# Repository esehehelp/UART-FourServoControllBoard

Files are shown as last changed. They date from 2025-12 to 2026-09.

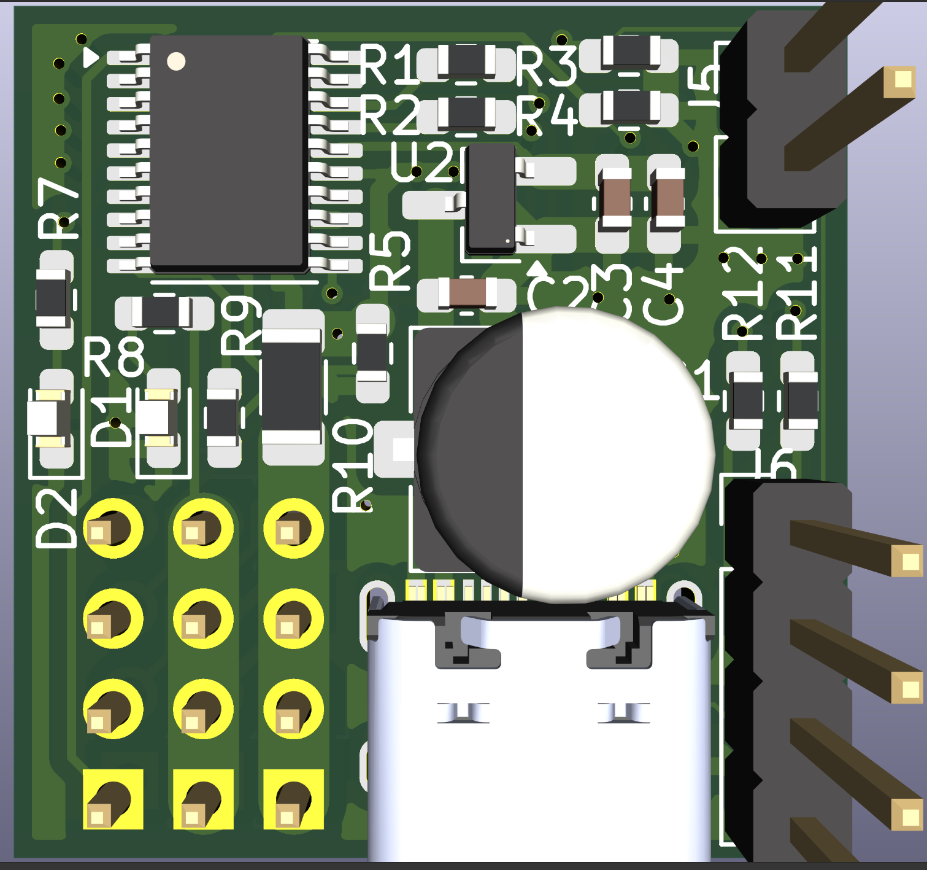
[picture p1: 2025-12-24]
hardware/img/boardfrontview.png

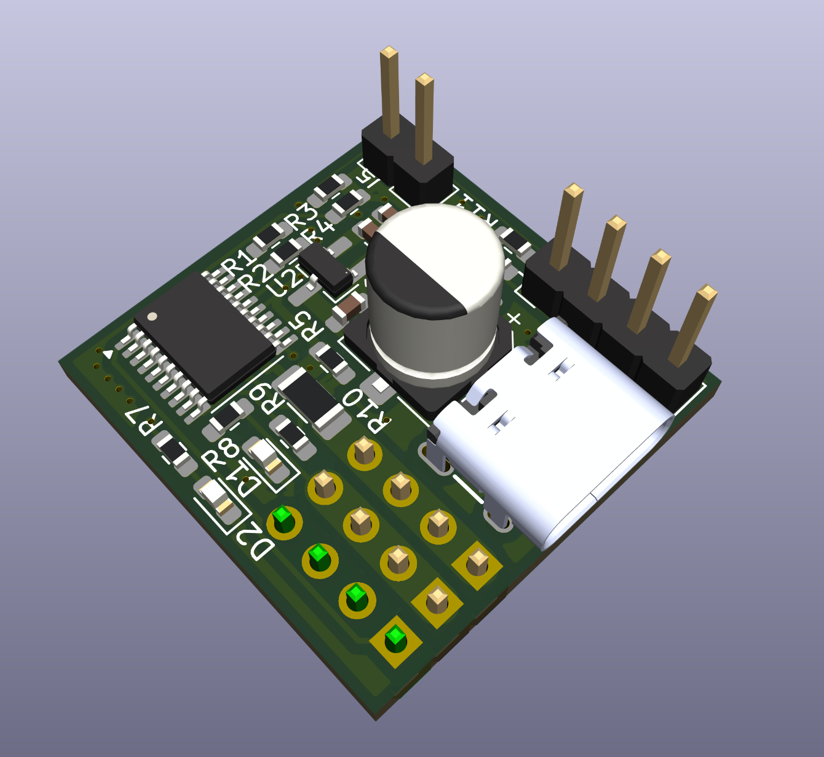
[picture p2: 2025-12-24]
hardware/img/board25dview.png

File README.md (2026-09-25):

# UART-FourServoControllBoard

## 概要 (Overview)

**UART-FourServoControllBoard** (以下UART-FSCB) は、わずか **22.82mm x 23.62mm** のサイズに、ロボットアーム制御に必要な機能をおおよそ詰め込んだ4軸スマートサーボコントローラ
従来のPCA9685等の単なるPWMドライバとは異なり、**電流・電圧・温度監視**、**USB-PD** 機能を搭載。MG996Rなどのハイパワーサーボ使用時でも、電流値と消費電力を監視しながら安全に駆動することが可能

## 特徴 (Features)

* **超小型サイズ:** 22.82mm x 23.62mm
* **USB PD対応:** CCピン制御により、モバイルバッテリーやPD充電器から電源を直接引き出し可能
  * 固定電圧 PDO に加え PPS (APDO) による電圧指定に対応 (`0x06` コマンド, mV 単位)
  * USB (CDC) 経由の通信対応
  * DLM (ブートローダ) 移行: `0xF0` コマンド、または背面PADに4.7k抵抗を直列でショート
    * USB経由の書き込み可能
* **電流監視機能:**
  * ローサイド電流検知回路を搭載（CH32X035内蔵OPA + 10mΩシャント抵抗）
  * サーボの負荷状態をモニタリングし、過負荷時の緊急停止などが実装可能
  * 停止閾値などは別途ソフトウェアで書き込み可能
* **電圧監視機能**
  * 分圧抵抗によって電圧を監視可能
  * PPSと組み合わせたフィードバック制御も行う予定
* **温度監視**
  * NTCサーミスタによってVBUS-GNDに近い位置の温度計測が可能
* **PC用GUI** (`software/`)
  * Go + Wails (React) 製。USB 接続したボードを自動検出
  * 電圧・電流・温度・サーボフィードバックのリアルタイムプロット
  * サーボ 4ch / LED 2ch / USB-PD 電圧の操作、サーボ位置キャリブレーション
* **MCU:** WCH CH32X035F7P6 (RISC-V, 48MHz)
* **制御IF:** 1Wire-UART, USB
* **その他:**
  * 外部電源入出力ピンヘッダx2 (バッテリー駆動対応、BMS無し)
  * デイジーチェーン対応 (1Wire-UARTかつ電源ピン仕様時)
  * デバック用1.27ピンヘッダ搭載
  * 片面実装
  * 手ハンダ可能 (難易度は高い)
  * XC6206 LDOによる安定した3.3V系電源
    * より高耐圧な互換LDOによるさらなる高電圧対応

## 仕様 (Specifications)

| 項目 | 内容 |
| :--- | :--- |
| **MCU** | WCH CH32X035F7P6 (TSSOP-20) |
| **入力電圧** | USB VBUS (5V-20V) または EXT_IN (5V〜20V) |
| **ロジック電圧** | 3.3V (XC6206 LDO内蔵) |
| **出力チャンネル** | 4PWM |
| **通信** | 1-Wire UARTx2 (Default: 115200bps, 8N1) |
| **電流検知** | 0 〜 6.8A (Full Scale) |
| **コンデンサ** | 100uF / 35V (Polymer) + 22uF (Ceramic) |
| **基板サイズ** | 22.86mm x 23.62mm |

### サーボチャンネルと物理ピン

チャンネル番号は基板上のピン並び順と一致しません (ピン番号順に **CH3 → CH0 → CH1 → CH2**)。

| MCU ピン No. | MCU ピン | チャンネル |
| :--- | :--- | :--- |
| 5 | PC1 | CH3 |
| 6 | PA0 | CH0 |
| 7 | PA1 | CH1 |
| 9 | PA3 | CH2 |

## リポジトリ構成

| ディレクトリ | 内容 |
| :--- | :--- |
| `firmware/` | CH32X035 用ファームウェア (PlatformIO)。通信仕様は [`firmware/docs/PROTOCOL.md`](firmware/docs/PROTOCOL.md) |
| `software/` | PC 用 GUI (Go + Wails)。詳細は [`software/README.md`](software/README.md) |
| `hardware/` | KiCad 9.0 設計データ |

## 開発環境 (Development)

* **IDE:** Goland, CLion
* **Firmware:** PlatformIO (`platform = ch32v`)
* **Writer:** WCH-LinkE、または USB 経由 (DLM + wchisp)

### ファームウェアのビルド・書き込み

```bash
cd firmware
pio run                 # ビルド
pio run -t upload       # WCH-LinkE 等で書き込み

# USB 経由 (0xF0 で DLM に移行してから wchisp で書き込み)
python test/dlm_upload.py <PORT> .pio/build/genericCH32X035F7P6/firmware.bin
```

### GUI のビルド

```bash
cd software
~/go/bin/wails build    # -> build/bin/servo-controller (Wails CLI が必要)
go test ./pkg/... ./test/...   # Go ユニットテスト
```

## 設計データ (Design Data)

* **EDA:** KiCad 9.0
* **PCB:** 2層基板 (1.6mm厚推奨)

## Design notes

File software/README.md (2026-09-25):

# Servo Controller GUI (Go + Wails)

UART-FSCB を USB 経由で操作・監視する PC 用 GUI。バックエンドは Go、フロントエンドは React (TypeScript) で、[Wails v2](https://wails.io/) で 1 つの実行ファイルにまとめています。

## 機能

- **自動接続**: シリアルポートを走査し、`0x02` (センサー読み出し) に応答したポートに接続
  - ボードの USB VID (WCH `0x1A86`) を持つポート → その他の USB ポート → `ttyUSB` → `ttyACM` / `COM*` → `ttyS` の順に試行
- **リアルタイムモニタリング** (~30 fps)
  - 電圧 (V)・電流 (mA)・温度 (°C)・サーボフィードバック CH0-3
  - 電圧・電流は Kalman フィルタで平滑化
  - 2 秒間応答がないとデータを無効扱いにし、ステータスバーに "No sensor data" を表示
- **サーボ制御** (`0x01`): 4ch スライダー、500–2500 µs (ファームウェアのデフォルト範囲)
- **LED 制御** (`0x30`): LED1 / LED2 それぞれ 0–255
- **USB-PD 電圧** (`0x06`): 5 / 9 / 15 / 20 V プリセット + 任意電圧 (mV)
- **位置キャリブレーション** (`0x07`)
  1. サーボをセンター (1500 µs) へ移動
  2. PWM を停止 (`0x09`) し、ユーザがアームを最小位置へ動かして Confirm
  3. 最大位置へ動かして Confirm
  4. 2 点のフィードバック値から傾き・切片を計算しフラッシュへ保存

チャンネル番号と基板上のピンの対応は [`firmware/docs/PROTOCOL.md`](../firmware/docs/PROTOCOL.md) を参照してください。

## ビルド

### 前提条件

- Go (go.mod 参照)
- Node.js / npm (フロントエンド)
- Wails CLI v2: `go install github.com/wailsapp/wails/v2/cmd/wails@latest`
- Linux の場合は Wails の依存パッケージ (GTK3, WebKit2GTK)。`wails doctor` で確認できます
- シリアルポートアクセスのため CGO が必要

### コマンド

```bash
cd software

~/go/bin/wails build                          # -> build/bin/servo-controller
~/go/bin/wails build -platform windows/amd64  # Windows 向け
~/go/bin/wails dev                            # ホットリロード付き開発サーバ
go test ./pkg/... ./test/...                  # Go ユニットテスト
```

## プロジェクト構成

```
software/
├── main.go                    # Wails アプリ起動
├── app.go                     # JS から呼べるメソッド、イベント送出 (~30 fps)
├── config/config.go           # プロトコル定数・スケール係数・各種パラメータ
├── pkg/
│   ├── serial/manager.go      # パケット (Marshal/Unmarshal, CRC8)、ポート検出、送受信 goroutine
│   ├── device/controller.go   # 高レベル API (SetServo, SetLED, ...)、センサーデータ解析
│   ├── device/packet.go       # pkg/serial のパケット型のエイリアス
│   ├── data/ringbuffer.go     # スレッドセーフなリングバッファ + 1D Kalman フィルタ
│   └── calibration/           # 位置キャリブレーションの状態機械
├── frontend/src/              # React UI (StatusBar, ServoControl, LEDControl, PDControl,
│                              #           CalibrationPanel, SensorGraph)
└── test/                      # パケットのユニットテスト
```

## 通信フロー

```
React UI ──(Wails binding)──> App ──> Controller ──> serial.Manager ──> USB-CDC ──> Firmware
React UI <──(Wails events)─── App <── Controller <── rx channel     <──
```

- `serial.Manager` は受信 goroutine でパケットを切り出し、容量 128 の channel に流します (溢れた場合はログに累計破棄数を出力)
- `Controller` は受信パケットの処理と定期的なセンサー要求を 1 つの goroutine で行います
- フロントエンドへは `sensor-data` / `plot-data` / `status` / `cal-status` イベントで通知します

## プロトコル

パケット形式・コマンド一覧は [`firmware/docs/PROTOCOL.md`](../firmware/docs/PROTOCOL.md) を参照してください。

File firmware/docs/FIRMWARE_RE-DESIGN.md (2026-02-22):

# CH32X035F7P6 ファームウェア設計変更ログ

## ハードウェア制約と解決策
- **ピン数**: TSSOP20 (F7P6) のためリマップが必須。
- **USART2 vs PWM**: PA3 で USART2_RX がデフォルトだが、サーボ PWM と競合する。
  - **解決**: USART2 を 1-Wire Half-Duplex に設定し、RXピンを使用しない構成とする。さらにリマップにより論理的なRXピンを PA5 側へ逃がす（実際には USART4 と共有）。
- **USART4 (UART_B)**: PA5 を 1-Wire TX として使用するため、`AFIO_PCFR1` でリマップを適用。
- **OPA2 vs UART**: PA2 (USART2_TX) と PA5 (USART4_TX) が OPA2 のピンと重なっている。
  - **解決**: OPA2 を内部出力モード (`MODE2=0`) に設定して PA2 を解放し、負入力 (`NSEL2=111`) を切り替えて PA5 を解放。

## ソフトウェア設計
- **時間管理の移行**: `Delay_Ms` (SysTick) との干渉を避けるため、プロジェクト全体の時間管理を `TIM3` (1ms割り込み) に移行。
- **プロトコルスタック**: 全ての UART/USB インターフェースで共通のパーサーを使用し、リングバスを構成。
- **USB PD**: PPS 対応を完了。起動時は必ず 5V で安全を確保。

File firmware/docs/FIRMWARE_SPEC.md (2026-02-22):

# CH32X035F7P6 ファームウェア仕様 (v2.1)

## 1. 周辺機能の割り当て
| 機能 | 周辺機能 | ピン / チャンネル | 備考 |
| :--- | :--- | :--- | :--- |
| **Servo CH0** | TIM2_CH1 | PA0 | |
| **Servo CH1** | TIM2_CH2 | PA1 | |
| **Servo CH2** | TIM2_CH4 | PA3 | |
| **Servo CH3** | TIM1_CH2 | PC1 | Full Remap 適用 |
| **UART_A** | USART2 | PA2 | 1-Wire モード |
| **UART_B** | USART4 | PA5 | 1-Wire モード / Partial Remap 1 |
| **V_SENSE** | ADC_IN6 | PA6 | 電圧監視 (5.1k/1k分圧) |
| **T_SENSE** | ADC_IN9 | PB1 | 温度監視 (NTC 22k) |
| **I_SENSE** | OPA2 / ADC_IN4 | PA7(+) / PA4(O) | 電流監視 (10mOhm / PGA x32) |
| **LED** | GPIO | PB12 | ステータス表示 (Active-High) |
| **1ms Tick** | TIM3 | 内部 | 時間管理・DLMカウントダウン用 |

## 2. UART 構成とリマップ
- **USART2 (PA2)**: デフォルト設定。`HDSEL` ビットにより 1-Wire モードで使用。
- **USART4 (PA5)**: `AFIO_PCFR1` の `USART4_REMAP` ビットを `001` に設定し、TX 機能を PA5 に割り当て。同様に `HDSEL` で 1-Wire 運用。
- **パケットルーティング**: 受信したパケットのターゲットIDが自ノードでない場合、受信したポート以外（UART2, UART4, USB）へパケットをブリッジします。

## 3. OPA2 と電流計測
- **構成**: PGA モード、ゲイン x32。
- **ピン競合回避**: 
  - `MODE2 = 0` により OPA2 出力を内部の PA4 (ADC_IN4) に固定し、USART2 で使用する PA2 を解放。
  - `NSEL2 = 111` により負入力を PA5 から切り離し、USART4 で使用する PA5 を解放。

## 4. 時間管理
- **TIM3**: 1ms 周期の割り込みを生成。
- **用途**: センサーデータの受信タイムアウト監視、DLM（ISPモード）移行への秒数カウント、将来的な時間ベースの制御用。
- **Delay**: 標準の `Delay_Ms` は SysTick を停止させるため、経過時間の計測には TIM3 のカウント（`g_ms_ticks`）を使用すること。

## 5. ファームウェアアップデート (DLM)
- **トリガー**: UART コマンド `0xF0`。
- **シーケンス**:
    1. `0xF0` 受信後、`g_dlm_requested` フラグをセット。
    2. LED が高速点滅 (5Hz)。
    3. 約2秒後、ソフトウェアリセットを実行し、System Bootloader (ISP) モードへ移行。
- **ツール**: `wchisp` または `WCHISPTool`。

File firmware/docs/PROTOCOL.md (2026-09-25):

# UART Four Servo Control Board 通信プロトコル仕様 (v2.3)

## 1. 物理層
- **通信方式**: 1-Wire 半二重 UART (Ring Bus 構成)
- **インターフェース**: USB (CDC), UART2, UART4
- **ボーレート**: 115200 bps (8N1)
- **デフォルトデバイスID**: `0x01` (ホストは `0x00`, ブロードキャストは `0xFF`)

## 2. パケット構造
すべてのパケットは以下の形式で構成されます。数値は特に指定がない限りビッグエンディアン（Big-Endian）です。

| Offset | Field | Value | Description |
| :--- | :--- | :--- | :--- |
| 0 | Header | 0xAA | パケット開始フラグ |
| 1 | Target ID | 0xXX | 送信先デバイスID |
| 2 | Source ID | 0xXX | 送信元デバイスID |
| 3 | Command | 0xXX | 命令コード |
| 4 | Length | N | データ部のバイト数 |
| 5..5+N-1 | Data | ... | 命令に応じたデータ |
| 5+N | CRC8 | 0xXX | HeaderからData末尾までのCRC |

- **最大パケット長**: 128 bytes (ファームウェアの受信バッファ長)。したがって Data 部 (N) は最大 **122 bytes**。
  Length に 122 を超える値を持つパケットはファームウェアで破棄されます。

### サーボチャンネルと物理ピンの対応
チャンネル番号はタイマーチャンネルの割り当て順であり、基板上のピン並び順とは一致しません。

| 物理ピン (MCU pin No.) | MCU ピン | チャンネル | タイマー |
| :--- | :--- | :--- | :--- |
| 5 | PC1 | **CH3** | TIM1_CH2 (Full Remap) |
| 6 | PA0 | **CH0** | TIM2_CH1 |
| 7 | PA1 | **CH1** | TIM2_CH2 |
| 9 | PA3 | **CH2** | TIM2_CH4 |

ピン番号順に並べると **CH3 → CH0 → CH1 → CH2** となります (`firmware/docs/pinassign.csv` 参照)。

## 3. 命令コード (Command)

### 0x01: Write (サーボ個別設定)
特定のチャンネルのサーボパルス幅を設定します。
電源投入直後は全チャンネルが PWM 停止 (出力 LOW、`0x09` と同じ状態) で、`0x01` / `0x03` を受信したチャンネルから駆動を開始します。
パルス幅はチャンネルごとのキャリブレーション範囲 (デフォルト 500-2500μs) にクランプされます。
- **Data**: 3 bytes
  - `[0]`: Channel Index (0-3)
  - `[1:2]`: Pulse Width (uint16, 500-2500μs)

### 0x02: Read (センサー読み出し)
各種センサー情報とサーボの現在位置を取得します。
- **Request Data**: 1 byte (0x00: All)
- **Response Data (0x82)**: 15 bytes
  - `[0]`: Data Type (0x00)
  - `[1:2]`: Bus Voltage (ADC Raw Value)
  - `[3:4]`: MCU Temperature (ADC Raw Value)
  - `[5:6]`: Total Current (ADC Raw Value)
  - `[7:14]`: Servo 0-3 Feedback (μs, 16-bit x 4 channels)
    - 保存されたキャリブレーション係数を用いて計算された値が返ります。

### 0x03: SyncWrite (全サーボ同時設定)
全4チャンネルのパルス幅を一度に設定します。
- **Data**: 8 bytes
  - `[0:1]`: CH0 Pulse, `[2:3]`: CH1 Pulse, `[4:5]`: CH2 Pulse, `[6:7]`: CH3 Pulse (all uint16)

### 0x04: CfgWrite (システム設定)
デバイス自体の設定を変更します。
- **Sub-Commands**:
  - `[0:1] = [0x01, NewID]`: デバイスIDを変更し、Flashに保存します。
  - `[0:1] = [0x02, Role]`: デバイスのロールを変更し、Flashに保存します。

### ~~0x05: STATIC_LED~~ (廃止 → `0x30` に移行)

### 0x30: LED_SET (LED制御)
基板上のインジケータLEDを個別に制御します。
- **Data**: 2 bytes
  - `[0]`: Channel (0=LED1/PB12/Active-High, 1=LED2/PC3/Active-Low)
  - `[1]`: Duty (0-255, soft PWM)

### 0x06: Set Voltage (USB PD PPS設定)
USB PD PPS対応電源を使用している場合、供給電圧を変更します。
- **Data**: 2 bytes
  - `[0:1]`: Target Voltage (uint16, unit: mV)

### 0x07: Set Calibration (キャリブレーション保存)
特定チャンネルのキャリブレーションパラメータと安全範囲を Flash に保存します。
- **Data**: 13 bytes
  - `[0]`: Channel Index (0-3)
  - `[1:4]`: Slope (float32, little-endian)
  - `[5:8]`: Intercept (float32, little-endian)
  - `[9:10]`: Min Pulse (uint16, big-endian)
  - `[11:12]`: Max Pulse (uint16, big-endian)
- Slope / Intercept はファームウェアが `memcpy` で float に直接コピーするため **little-endian** です (パケット全体の既定であるビッグエンディアンの例外)。
- `Min Pulse >= Max Pulse` のデータは無視され、保存されません。

### 0x08: Get Calibration (キャリブレーション取得)
保存されている設定を読み出します。
- **Request Data**: 1 byte (Channel Index)
- **Response Data (0x88)**: 13 bytes (0x07 と同形式)

### 0x09: Servo Free (PWM停止)
指定チャンネルのPWM出力を停止し、サーボを脱力させます。再度動かすには `0x01` または `0x03` を送信します。
- **Data**: 1 byte (ch_mask: bit0=CH0, bit1=CH1, bit2=CH2, bit3=CH3)

### 0xA0: Ping (デバイス探索要求)
リングバス上のデバイスを探索します。動作は受信したボードのロール (`0x04` CfgWrite の Role) によって異なります。
- **Data**: なし (0 bytes)
- **ROLE_HOST (0x01) のボードが USB から受信した場合**:
  Target=`0xFF` (ブロードキャスト)、Source=自身のデバイスID で Ping を UART2 (リング下流) へ送信し、100 ms の探索ウィンドウを開始します。
- **ROLE_DEVICE (0x00) のボードが受信した場合**:
  受信したインターフェースへ `0xA1` (Pong) を返信します (Target=Ping の Source、Data=`[device_id]`)。

### 0xA1: Pong (デバイス探索応答)
- **デバイス → ホストボード**: Data 1 byte (`[0]`: 応答したデバイスのID)。
  ROLE_HOST のボードは探索ウィンドウ中に受信した ID を最大 16 個まで記録します。
- **ホストボード → PC (USB)**: 探索開始から 100 ms 経過後、Target=`0x00` で送信します。
  - **Data**: N bytes (N = 発見したデバイス数、0-16)。各バイトが発見したデバイスID。

> 注: 現在の実装では、ブロードキャスト (`0xFF`) 宛パケットは受信したデバイスで実行され、リングの次段へは転送されません。

### 0xF0: DLM (Download Mode)
ブートローダー(ISP)モードへ移行するためのカウントダウンを開始します。

## 4. CRC8 計算
- **多項式**: `0x07` (x^8 + x^2 + x + 1)
- **初期値**: `0x00`
- **対象**: Header から Data の末尾まで

```c
uint8_t crc8(const uint8_t *data, size_t len) {
    uint8_t crc = 0;
    for (size_t i = 0; i < len; i++) {
        crc ^= data[i];
        for (int j = 0; j < 8; j++) {
            if (crc & 0x80) crc = (crc << 1) ^ 0x07;
            else crc <<= 1;
        }
    }
    return crc;
}
```

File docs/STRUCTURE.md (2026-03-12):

# Documentation Structure

## 既存ドキュメント配置

### Root Level
- **README.md** - プロジェクト概要 (特徴・仕様・開発環境)
- **CLAUDE.md** - AI向けコンテキスト

### firmware/docs/
- **PROTOCOL.md** - プロトコル仕様詳細
- **FIRMWARE_SPEC.md** - ファームウェア機能仕様
- **FIRMWARE_RE-DESIGN.md** - 再設計ノート
- **pinassign.csv** - ピンアサイン（簡略版）

### software/
- **README.md** - Go GUI機能説明

### docs/ (新規)
- **PINASSIGN_VERIFIED.csv** - ソースコード検証版ピンアサイン
- **STRUCTURE.md** - このファイル

## 整理指針

各ドキュメントは機能要件・問題ごとに分離されるべき:

1. **PROTOCOL.md** - コマンド仕様のみ
2. **FIRMWARE_SPEC.md** - モジュール機能のみ
3. **pinassign.csv** - 既存版は簡略版、PINASSIGN_VERIFIED.csvはソース検証版
4. **README.md** - 全体概要のみ
5. **software/README.md** - GUI機能説明のみ

汎用的な「統一ドキュメント」は不要。各ドキュメントは独立して参照可能であること。

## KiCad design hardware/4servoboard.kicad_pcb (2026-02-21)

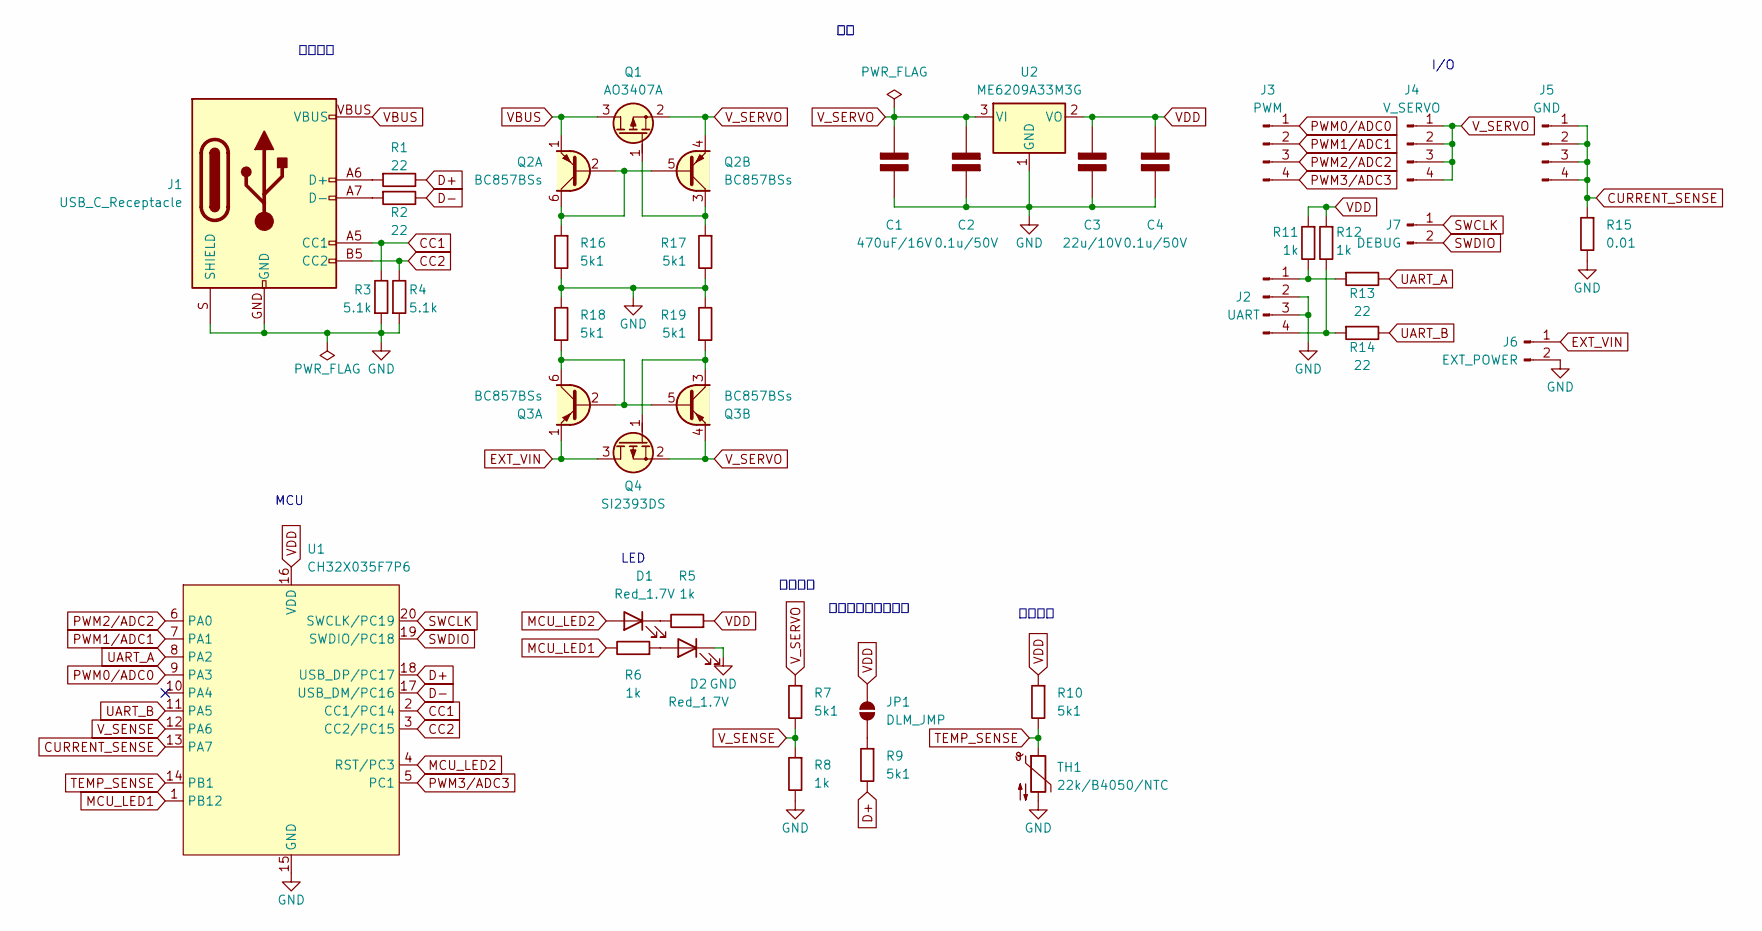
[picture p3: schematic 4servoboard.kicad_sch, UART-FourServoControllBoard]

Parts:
C1: 470uF/16V; CP_Elec_6.3x7.7; Rating V
C2, C4: 0.1u/50V; C_0603_1608Metric; Rating V
C3: 22u/10V; C_0603_1608Metric; Rating V
D1, D2: Red_1.7V; LED_0603_1608Metric
J1: USB_C_Receptacle; USB-C_16-HandSolder
J2: UART; PinHeader_1x04_P2.54mm_Vertical
J3: PWM; PinHeader_1x04_P2.54mm_Vertical
J4: V_SERVO; PinHeader_1x04_P2.54mm_Vertical
J5: GND; PinHeader_1x04_P2.54mm_Vertical
J6: EXT_POWER; TerminalBlock_Xinya_XY308-2.54-2P_1x02_P2.54mm_Horizontal
J7: DEBUG; PinHeader_1x02_P2.54mm_Vertical
JP1: DLM_JMP; SolderJumper-2_P1.3mm_Open_Pad1.0x1.5mm
Q1: AO3407A; SOT-23
Q2, Q3: BC857BSs; SOT-363_SC-70-6
Q4: SI2393DS; SOT-23
R1, R2, R13, R14: 22; R_0603_1608Metric
R3, R4: 5.1k; R_0603_1608Metric
R5, R6, R8, R11, R12: 1k; R_0603_1608Metric
R7, R9, R10, R16, R17, R18, R19: 5k1; R_0603_1608Metric
R15: 0.01; R_1206_3216Metric
TH1: 22k/B4050/NTC; R_0603_1608Metric
U1: CH32X035F7P6; TSSOP-20_4.4x6.5mm_P0.65mm
U2: ME6209A33M3G; SOT-23

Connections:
CC1: J1.A5 (CC1), R3.2, U1.2 (CC1/PC14)
CC2: J1.B5 (CC2), R4.2, U1.3 (CC2/PC15)
CURRENT_SENSE: J5.1, J5.2, J5.3, J5.4, R15.1, U1.13 (PA7)
D+: R1.2, R9.2, U1.18 (USB_DP/PC17)
D-: R2.2, U1.17 (USB_DM/PC16)
EXT_VIN: J6.1, Q3.1 (E1), Q4.3 (D)
GND: C1.2 (-), C2.1 (+), C3.2 (-), C4.2 (-), D2.1 (K), J1.GND, J1.S (SHIELD), J2.2, J2.3, J6.2, R3.1, R4.1, R8.2, R15.2, R16.2, R17.2, R18.2, R19.2, TH1.2, U1.15 (GND), U2.1 (GND)
MCU_LED1: R6.2, U1.1 (PB12)
MCU_LED2: D1.2 (A), U1.4 (RST/PC3)
unnamed: D1.1 (K), R5.2
unnamed: D2.2 (A), R6.1
unnamed: J1.A6 (D+), J1.B6 (D+), R1.1
unnamed: J1.A7 (D-), J1.B7 (D-), R2.1
unnamed: J2.1, R11.2, R13.1
unnamed: J2.4, R12.2, R14.1
unnamed: JP1.1 (A), R9.1
unnamed: Q1.1 (G), Q2.3 (C2), R17.1
unnamed: Q2.2 (B1), Q2.5 (B2), Q2.6 (C1), R16.1
unnamed: Q3.2 (B1), Q3.5 (B2), Q3.6 (C1), R18.1
unnamed: Q3.3 (C2), Q4.1 (G), R19.1
PWM0/ADC0: J3.1, U1.9 (PA3)
PWM1/ADC1: J3.2, U1.7 (PA1)
PWM2/ADC2: J3.3, U1.6 (PA0)
PWM3/ADC3: J3.4, U1.5 (PC1)
SWCLK: J7.1, U1.20 (SWCLK/PC19)
SWDIO: J7.2, U1.19 (SWDIO/PC18)
TEMP_SENSE: R10.2, TH1.1, U1.14 (PB1)
UART_A: R13.2, U1.8 (PA2)
UART_B: R14.2, U1.11 (PA5)
VBUS: J1.VBUS, Q1.3 (D), Q2.1 (E1)
VDD: C3.1 (+), C4.1 (+), JP1.2 (B), R5.1, R10.1, R11.1, R12.1, U1.16 (VDD), U2.2 (VO)
V_SENSE: R7.2, R8.1, U1.12 (PA6)
V_SERVO: C1.1 (+), C2.2 (-), J4.1, J4.2, J4.3, J4.4, Q1.2 (S), Q2.4 (E2), Q3.4 (E2), Q4.2 (S), R7.1, U2.3 (VI)

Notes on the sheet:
電圧計測
MCU
I/O
温度計測
LED
コネクタ
ダウンロードモード

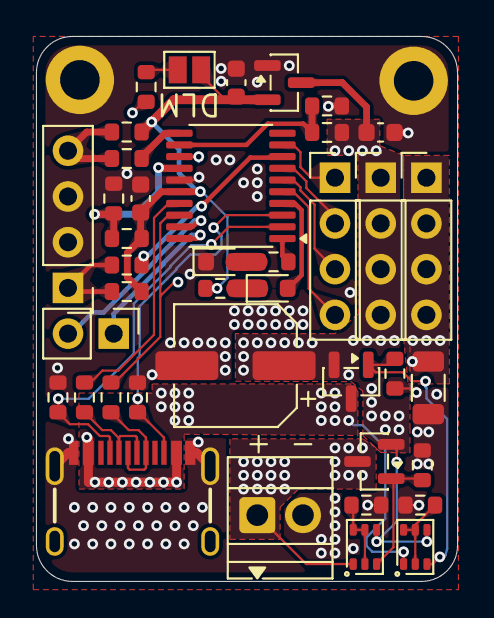
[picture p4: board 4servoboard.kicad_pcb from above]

Board: 4 copper layers, 23.4 x 30.3 mm, 40 parts (0 on the bottom side), 33 nets.

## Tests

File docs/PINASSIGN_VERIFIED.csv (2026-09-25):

" Pin Assignment - Verified from Source Code Source code verified pin assignments for CH32X035F7P6 (TSSOP-20) All peripheral mappings extracted from firmware source files. "
Pin | Port | MCU Function | Hardware Use | Peripheral | ADC Channel | Source File | Notes
1 | PB12 | GPIO | LED1 | GPIO_Out_PP | none | led.c:9 | Active-High LED output
2 | PC14 | USB-PD CC1 | CC1 | USB-PD | none | usb_pd.c | USB-PD CC1 — implemented; voltage negotiation and PPS support (usb_pd.c)
3 | PC15 | USB-PD CC2 | CC2 | USB-PD | none | usb_pd.c | USB-PD CC2 — implemented; voltage negotiation and PPS support (usb_pd.c)
4 | PC3 | GPIO | LED2 | GPIO_Out_PP | none | led.c:16 | Active-Low; CMP1_N0 must be disabled (led.c:39)
5 | PC1 | TIM1_CH2 | Servo CH3 PWM + FB | TIM1 (Full Remap) | ADC_CH11 | servo.c:45 | Full Remap AFIO PCFR1[17:15]=011
6 | PA0 | TIM2_CH1 | Servo CH0 PWM + FB | TIM2_CH1 | ADC_CH0 | adc.h:12 | Servo 0 output and feedback ADC
7 | PA1 | TIM2_CH2 | Servo CH1 PWM + FB | TIM2_CH2 | ADC_CH1 | adc.h:13 | Servo 1 output and feedback ADC
8 | PA2 | USART2_TX/RX | UART Ring (Upstream) | USART2 (1-Wire) | none | UART.c:L20 | 1-Wire Ring topology Upstream; 115200 bps 8N1
9 | PA3 | TIM2_CH4 | Servo CH2 PWM + FB | TIM2_CH4 | ADC_CH3 | adc.h:14 | Servo 2 output and feedback ADC
10 | PA4 | OPA2_OUT | Current Sense | OPA2 Output + ADC | ADC_CH4 | adc.h:9 | OPA2 current sense amplifier output
11 | PA5 | USART4_TX/RX | UART Ring (Downstream) | USART4 (Remap 001) | none | UART.c:L45 | 1-Wire Ring topology Downstream; Remap 001: AFIO PCFR1[4:3]=001
12 | PA6 | ADC input | Voltage Sense | ADC | ADC_CH6 | adc.h:7 | Power supply voltage measurement (6.1:1 divider)
13 | PA7 | OPA2_P0 | Current Sense Input | OPA2 Non-Inverting | none | adc.c:L20 | Shunt resistor (10mΩ) output to OPA2 input
14 | PB1 | ADC input | Temperature Sense | ADC | ADC_CH9 | adc.h:8 | NTC thermistor temperature measurement
15 | GND | Ground | Ground | Power | none |  | -
16 | VDD | Supply | 3.3V | Power | none | servo.c:36 | XC6206 LDO output (5-20V input → 3.3V)
17 | PC16 | USB | USB D- | USB | none | protocol.h | USB 2.0 Full-Speed
18 | PC17 | USB | USB D+ | USB | none | protocol.h | USB 2.0 Full-Speed
19 | PC18 | SWD | Debug SWDIO | Debug (SWD) | none | - | JTAG/SWD Debug Port
20 | PC19 | SWD | Debug SWCLK | Debug (SWD) | none | - | JTAG/SWD Debug Port

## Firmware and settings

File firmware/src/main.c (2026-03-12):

#include "debug.h"
#include "ch32x035_usbfs_device.h"
#include "UART.h"
#include "servo.h"
#include "adc.h"
#include "protocol.h"
#include "app.h"
#include "dlm_jump.h"
#include "usb_pd.h"
#include "led.h"
#include "usb_desc.h"
#include <stdio.h>

volatile uint32_t g_ms_ticks = 0;

/* Build USB serial number string from chip unique ID (0x1FFFF7E8, 8 bytes)
 * MySerNumInfo format: [len=0x22][type=0x03][16 hex chars in UTF-16LE] */
static void USB_BuildSerialFromUID(void) {
    static const char hex[] = "0123456789ABCDEF";
    const uint8_t *uid = (const uint8_t *)0x1FFFF7E8;
    for (int i = 0; i < 8; i++) {
        MySerNumInfo[2 + i*4 + 0] = hex[(uid[i] >> 4) & 0xF];
        MySerNumInfo[2 + i*4 + 1] = 0;
        MySerNumInfo[2 + i*4 + 2] = hex[uid[i] & 0xF];
        MySerNumInfo[2 + i*4 + 3] = 0;
    }
}
volatile uint32_t g_dlm_timer = 0;

void TIM3_IRQHandler(void) __attribute__((interrupt("WCH-Interrupt-fast")));
void TIM3_IRQHandler(void) {
    if (TIM_GetITStatus(TIM3, TIM_IT_Update) != RESET) {
        g_ms_ticks++;
        if (g_dlm_requested && g_dlm_timer > 0) {
            g_dlm_timer--;
        }
        TIM_ClearITPendingBit(TIM3, TIM_IT_Update);
    }
}

void Timer3_Init(void) {
    TIM_TimeBaseInitTypeDef TIM_TimeBaseStructure = {0};
    RCC_APB1PeriphClockCmd(RCC_APB1Periph_TIM3, ENABLE);
    TIM_TimeBaseStructure.TIM_Period = 1000 - 1;
    TIM_TimeBaseStructure.TIM_Prescaler = (SystemCoreClock / 1000000) - 1;
    TIM_TimeBaseStructure.TIM_ClockDivision = TIM_CKD_DIV1;
    TIM_TimeBaseStructure.TIM_CounterMode = TIM_CounterMode_Up;
    TIM_TimeBaseInit(TIM3, &TIM_TimeBaseStructure);
    TIM_ITConfig(TIM3, TIM_IT_Update, ENABLE);
    NVIC_EnableIRQ(TIM3_IRQn);
    TIM_Cmd(TIM3, ENABLE);
}

int main(void) {
    SystemCoreClockUpdate();
    Delay_Init();
    USART_Printf_Init(115200);
    printf("UART 4-Servo Board v2.0 Startup\r\n");

    USB_BuildSerialFromUID();
    USBFS_RCC_Init();
    USBFS_Device_Init(ENABLE, PWR_VDD_3V3);

    Protocol_Init(0x01);
    App_Init();
    Servo_Init();
    ADC_Init_Custom();
    
    // Initialize UARTs in Ring Mode (PA2=USART2, PA5=USART4, 1-Wire)
    UART_System_Init(UART_MODE_RING, 115200);
    
    USB_PD_Init();
    Timer3_Init();

    LED_Init();
    LED_StartupBlink();

    uint32_t last_ms = 0;

    while(1) {
        USB_PD_Process();

        // 1ms Tasks
        uint32_t now_ms = g_ms_ticks;
        if (now_ms != last_ms) {
            last_ms = now_ms;

            // Trigger ADC reading for servo feedback at 10ms into the 20ms period
            // Pulse is max 2.5ms at the start, so 10ms is safe.
            if ((now_ms % 20) == 10) {
                Update_Servo_Feedback();
            }

            App_Tick(now_ms);

            if (g_dlm_requested) {
                if (g_dlm_timer == 0) g_dlm_timer = 2000;
                if (g_dlm_timer <= 1800 && g_dlm_timer > 0) {
                    Jump_To_DLM(); // Reset into ISP
                }
            }
        }

        LED_Tick();

        // Poll UARTs
        if (USART_GetFlagStatus(USART2, USART_FLAG_RXNE) != RESET) {
            Process_Byte(IF_UART2, USART_ReceiveData(USART2));
        }
        if (USART_GetFlagStatus(USART2, USART_FLAG_ORE) != RESET) {
            USART_ReceiveData(USART2); // Clear ORE by reading DR
        }

        if (USART_GetFlagStatus(USART4, USART_FLAG_RXNE) != RESET) {
            Process_Byte(IF_UART4, USART_ReceiveData(USART4));
        }
        if (USART_GetFlagStatus(USART4, USART_FLAG_ORE) != RESET) {
            USART_ReceiveData(USART4); // Clear ORE by reading DR
        }
    }
}

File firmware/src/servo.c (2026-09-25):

#include "servo.h"
#include "config.h"

void Set_Servo(uint8_t idx, uint16_t pos) {
    if (idx >= 4) return;
    if (pos < g_config.cal[idx].min_pulse) pos = g_config.cal[idx].min_pulse;
    if (pos > g_config.cal[idx].max_pulse) pos = g_config.cal[idx].max_pulse;
    switch(idx) {
        case 0: TIM_SetCompare1(TIM2, pos); break;
        case 1: TIM_SetCompare2(TIM2, pos); break;
        case 2: TIM_SetCompare4(TIM2, pos); break;
        case 3: TIM_SetCompare2(TIM1, pos); break;
    }
}

// Servo_Free: set CCR to 0 so PWM1 output stays LOW entire period (servo goes limp).
// PWM mode and CCxE are untouched. Call Set_Servo() to re-engage.
void Servo_Free(uint8_t ch_mask) {
    if (ch_mask & 0x01) TIM_SetCompare1(TIM2, 0);
    if (ch_mask & 0x02) TIM_SetCompare2(TIM2, 0);
    if (ch_mask & 0x04) TIM_SetCompare4(TIM2, 0);
    if (ch_mask & 0x08) TIM_SetCompare2(TIM1, 0);
}

/* Servo Initialization - Nuclear Option for PA3 (Restored from main branch) */
void Servo_Init(void) {
    GPIO_InitTypeDef GPIO_InitStructure = {0};
    TIM_TimeBaseInitTypeDef TIM_TimeBaseStructure = {0};
    TIM_OCInitTypeDef TIM_OCInitStructure = {0};

    // 1. Enable Clocks
    RCC_APB2PeriphClockCmd(RCC_APB2Periph_GPIOA | RCC_APB2Periph_GPIOB | RCC_APB2Periph_GPIOC | RCC_APB2Periph_AFIO, ENABLE);
    RCC_APB1PeriphClockCmd(RCC_APB1Periph_TIM2 | RCC_APB1Periph_USART2, ENABLE);
    RCC_APB2PeriphClockCmd(RCC_APB2Periph_TIM1, ENABLE);
    
    // Enable OPA Clock directly (bit 22 of APB2PCENR)
    RCC->APB2PCENR |= (1 << 22);

    // 2. Explicitly DISABLE OPA1 (Outputs on PA3)
    // OPA_CTLR1: bit 0 is EN1.
    *((volatile uint32_t*)0x40026004) &= ~0x00000001; 

    // 3. Force TIM1 into Full Remap for PC1
    // TIM1_RM [17:15] = 011 (Full remap)
    AFIO->PCFR1 = (AFIO->PCFR1 & ~(0x7 << 15)) | (0x03 << 15);

    // 4. GPIO Setup
    GPIO_InitStructure.GPIO_Pin = GPIO_Pin_0 | GPIO_Pin_1 | GPIO_Pin_3;
    GPIO_InitStructure.GPIO_Mode = GPIO_Mode_AF_PP;
    GPIO_InitStructure.GPIO_Speed = GPIO_Speed_50MHz;
    GPIO_Init(GPIOA, &GPIO_InitStructure);

    GPIO_InitStructure.GPIO_Pin = GPIO_Pin_1;
    GPIO_Init(GPIOC, &GPIO_InitStructure);

    // 5. Timer Base Config
    TIM_TimeBaseStructure.TIM_Period = PWM_PERIOD - 1;
    TIM_TimeBaseStructure.TIM_Prescaler = (SystemCoreClock / 1000000) - 1;
    TIM_TimeBaseStructure.TIM_ClockDivision = TIM_CKD_DIV1;
    TIM_TimeBaseStructure.TIM_CounterMode = TIM_CounterMode_Up;
    TIM_TimeBaseInit(TIM1, &TIM_TimeBaseStructure);
    TIM_TimeBaseInit(TIM2, &TIM_TimeBaseStructure);

    // 6. OC Setup
    TIM_OCInitStructure.TIM_OCMode = TIM_OCMode_PWM1;
    TIM_OCInitStructure.TIM_OutputState = TIM_OutputState_Enable;
    TIM_OCInitStructure.TIM_Pulse = PWM_DEFAULT; // 0: servos free until commanded
    TIM_OCInitStructure.TIM_OCPolarity = TIM_OCPolarity_High;

    TIM_OC1Init(TIM2, &TIM_OCInitStructure);
    TIM_OC2Init(TIM2, &TIM_OCInitStructure);
    TIM_OC4Init(TIM2, &TIM_OCInitStructure);
    TIM_OC2Init(TIM1, &TIM_OCInitStructure);

    // 7. Enable Preload and MOE
    TIM_OC1PreloadConfig(TIM2, TIM_OCPreload_Enable);
    TIM_OC2PreloadConfig(TIM2, TIM_OCPreload_Enable);
    TIM_OC4PreloadConfig(TIM2, TIM_OCPreload_Enable);
    TIM_OC2PreloadConfig(TIM1, TIM_OCPreload_Enable);
    
    TIM_CtrlPWMOutputs(TIM1, ENABLE);
    TIM_CtrlPWMOutputs(TIM2, ENABLE);

    // 8. Start
    TIM_Cmd(TIM1, ENABLE);
    TIM_Cmd(TIM2, ENABLE);
}

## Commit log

2025-12-24 fix. ディレクトリ編成の大幅変更
    [4servoboard.kicad_pcb, 4servoboard.kicad_sch, BOM.csv]
2025-12-26 fix: README更新
2025-12-26 fix: ディレクトリ構成の変更に伴うパス修正
    [4servoboard.kicad_pcb, 4servoboard.kicad_sch, BOM.csv]
2025-12-26 fix: ディレクトリ構成の変更に伴うgitignoreの更新
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2026-01-29 wip: Rev0.4への更新
    [4servoboard.kicad_pcb, 4servoboard.kicad_sch]
2026-01-29 delete: 一部ファイルの削除
    [4servoboard-4x4.kicad_pcb, BOM.csv]
2026-01-29 fix: ファイル名変更に伴う.gitignore更新
2026-01-29 feat: V0.4移行、電源回路の強化
    [4servoboard.kicad_pcb]
2026-01-29 fix: V0.4移行に伴う部品構成の変更
2026-01-29 fix: typo修正
    [4servoboard.kicad_sch]
2026-02-07 Update: V0.6移行に伴い，四層基板ヘ移行．エラッタ修正，Pch逆接保護回路追加，5.08端子追加
    [4servoboard.kicad_pcb, 4servoboard.kicad_sch]
2026-02-08 Fix: 基板デザインの効率化が主．内容：アートワークの最適化，viaの追加など
    [4servoboard.kicad_pcb, 4servoboard.kicad_sch]
2026-02-09 Update: V0.7移行．ORing回路実装，電源設計の効率化，回路定数の見直し
    [4servoboard.kicad_pcb, 4servoboard.kicad_sch]
2026-02-14 Update: V0.8移行．回路設計の効率化．エラッタの修正
    [4servoboard.kicad_pcb, 4servoboard.kicad_sch]
2026-02-20 feat: ひとまずpwm生成できるように
    [pinassign.csv]
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2026-02-21 Configure dual 1-Wire UART (USART2 on PA2, USART4 on PA5) with correct remapping
    [UART.c]
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2026-02-21 Configure OPA2 to avoid PA2/PA5 conflicts and use internal ADC output
    [adc.c]
2026-02-21 Add Set Voltage command (0x06) and implement packet forwarding for ring bus
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2026-02-21 Add documentation and test scripts
    [pinassign.csv]
2026-02-22 Implement LED pattern playback, fix buffer overflows, and reorganize driver library
    [main.c, protocol.c]
2026-02-22 Finalize firmware with stable TIM3 timing, correct UART remapping, and updated Japanese documentation
    [pinassign.csv]
2026-02-22 fix: ディレクトリの修正
    [pinassign.csv]
2026-02-22 fix: 勝手に消された内容の復元
    [pinassign.csv]
2026-02-27 fix: resolve UART-A (PA2) pin conflict and PA3 PWM noise interference
    [UART.c, main.c]
2026-02-27 checkpoint: UART-B RX works, but TX and UART-A are failing
    [UART.c]
2026-03-11 feat: add servo position feedback via ADC during PWM idle periods
    - Implement Update_Servo_Feedback() to sample PA0, PA1, PA3, PC1 as ADC
    - Switch GPIO mode between AF_PP and AIN during PWM low periods (10ms offset)
    - Extend protocol 0x02 (Read Sensors) response from 7 to 15 bytes to include feedback
    - Update gui_control.py to display real-time feedback voltage for each channel
    - Update PROTOCOL.md to v2.2 reflecting packet structure changes
2026-03-11 Go + Fyne GUI実装開始: シリアル通信、パケット、UI基本実装
    - software/ディレクトリを新規作成
    - Go 1.26、Fyne v2で完全に再実装
    - pkg/serial/: UART通信管理（jacobsa/go-serialを使用）
    - pkg/device/: パケット処理、デバイス制御、センサーデータ解析
    - pkg/data/: リングバッファ、Kalmanフィルタ
    - pkg/ui/: Fyneウィジェット（サーボ、LED、PD制御）
    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
2026-03-11 Go Fyne GUI実装完了: グラフ、キャリブレーション、UI統合、テスト
    完成した機能：
    - pkg/ui/graph.go: シンプルなラインプロット実装（Fyneキャンバス使用）
    - pkg/calibration/state_machine.go: サーボキャリブレーション状態機械
    * 段階的なキャリブレーション流れ（Init→Coarse→Fine→Save）
    * リップル計測、限界検出、フラッシュ保存
    - CalibrationControl UI: キャリブレーション開始/停止ボタン
    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
2026-03-11 ビルドシステム構築: Makefile, build.sh, bin/ディレクトリ構成
    実装内容：
    - Makefile: クロスコンパイル対応（Linux/Windows 自動ビルド）
    - build.sh: Bash ビルドスクリプト（Linux/Windows、テスト実行）
    - software/.gitignore: bin/ ディレクトリと一時ファイルを除外
    - README.md: ビルド手順の詳細化
    ビルド出力構成：
    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
2026-03-11 Fyne スレッド安全性修正とグラフ表示実装
    修正内容:
    - **スレッド安全性**: バックグラウンド goroutine から直接 UI を更新していたエラーを修正
    - 別スレッドのデータ更新と、Fyne メインスレッドの UI 更新を分離
    - UpdateData() で Text フィールドに直接アクセスして Refresh() を呼ぶ方式に修正
    - **グラフコンポーネント完全実装**: LineChart と GraphCanvas を完全実装
    - 4つの線グラフ（電圧、電流、温度、サーボフィードバック）
    - データ点を正規化して描画（canvas.NewLine で線分描画）
    - リアルタイムデータ更新対応
    - **UI 更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
2026-03-12 firmware: CMD_SERVO_FREE (0x09) — CCR=0でサーボ脱力
    Servo_Free(ch_mask): TIM_SetCompare=0でPWM1出力を常時LOWにする。
    TIM_SelectOCxM/TIM_ForcedOCxConfigは使用しない（CCxEを壊すため）。
    Set_Servo()呼び出しで自動復帰、モードレジスタ変更なし。
    protocol.c: case 0x09でServo_Free(data[0])を呼び出す。
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2026-03-12 software/go.mod: Wails v2依存関係に更新
    Fyne v2 → Wails v2 + go.bug.st/serial v1.6.4。
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2026-03-12 software/frontend: React + TypeScript フロントエンド追加
    Wails v2対応。Recharts グラフ、キャリブレーション、サーボ/LED/PD制御UI。
    node_modules/ / dist/ / wailsjs/ は .gitignore で除外。
2026-03-12 firmware: リングバス通信 + デバイス探索 + USB iSerial修正
    - app.c/h: HOST/DEVICEロール別アプリ層 (0xA0 Ping/0xA1 Pong, 100ms discovery)
    - config.h/c: Config_tにroleフィールド追加、0x04サブコマンド0x02でロール設定
    - protocol.c/h: Forward_Packet修正 (USB→UART2, UART2→UART4, UART4→UART2)、0xA0/0xA1コマンド追加
    - usb_desc.c/h: iSerialNumber有効化 (0x00→0x03)、MySerNumInfoをRAM配列に変更
    - main.c: USB_BuildSerialFromUID()でチップUID(0x1FFFF7E8)からシリアル番号生成
    - test_ring.py: --set-host/--set-device/--discover CLIオプション追加
    [led.c, main.c, protocol.c]
2026-03-12 feat: implement teleoperate (0x0A) command for synchronized servo control
    - Add CMD_TELEOPERATE (0x0A) protocol command in protocol.h with command/response code constants
    - Implement teleoperate handler in Execute_Command() with MODE and CH_MASK support
    - MODE 0x00: Deactivate teleoperate mode
    - MODE 0x01: Activate teleoperate mode with channel mask
    - Add runtime teleoperate state struct (active flag, channel mask)
    - Teleoperate enables synchronized servo control between reader and follower devices
    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
2026-03-12 Revert: Remove teleoperate implementation
    This reverts commit aa13e32a0f1e0eec77b7d4be2c45f7302d012c38.
    [protocol.c]
2026-03-12 docs: Add source-verified pin assignment and structure guide
    - docs/PINASSIGN_VERIFIED.csv: Pin assignments verified from source code
    - All peripheral mappings extracted from firmware (servo.c, adc.c, led.c, UART.c)
    - References specific source files and line numbers
    - Distinguishes between PWM, ADC, and I/O functions
    - Includes remap configurations (TIM1 Full Remap, USART4 Remap 001)
    - docs/STRUCTURE.md: Documentation organization guide
    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
    [PINASSIGN_VERIFIED.csv]
2026-03-12 docs: fix CC1/CC2 pin assignment — mark USB-PD as implemented
    PINASSIGN_VERIFIED.csv の PC14/PC15 (CC1/CC2) が "not implemented" と
    誤記されていたのを修正する。usb_pd.c で電圧ネゴシエーション・PPS が
    実装済みであることを反映。MCU Function および Source File も合わせて修正。
    Closes #23
    [PINASSIGN_VERIFIED.csv]
2026-03-12 docs: fix factual errors in CLAUDE.md and PROTOCOL.md; update pinassign
    CLAUDE.md:
    - shunt resistance: 20mΩ → 10mΩ (V0.8 uses OPA2 PGA, confirmed by constants.txt)
    - remove ch32fun framework reference (commented out in platformio.ini)
    - command code range: 0x01-0x08 → 0x01-0x09 (CMD_SERVO_FREE 0x09 exists)
    firmware/docs/PROTOCOL.md:
    - 0x04: add role change sub-command [0x02, Role]
    - 0x05: correct Data field to 1-2 bytes (LED1 + LED2)
    - add missing 0x09 Servo Free command
    firmware/docs/pinassign.csv: update pin assignment
    [pinassign.csv]
2026-03-12 docs: add Git/GitHub workflow rules to CLAUDE.md
    ブランチ戦略、コミット規則、PR ルール、issue 運用方針、
    リリース成果物の記載フォーマットを追加。
2026-03-13 fix: packFloat32BE → LE でキャリブレーション float エンディアン修正 (closes #10)
    CH32X035 はリトルエンディアン RISC-V CPU のため、firmware の memcpy() は
    data バイト列をそのまま float メモリに展開する。従来の packFloat32BE は
    MSB ファーストで書いていたため slope/intercept がファームウェア側で常に
    化けていた (例: 1.0 → 2.35e-38)。
    - packFloat32BE → packFloat32LE にリネーム・実装修正
    - saveCalibration() のコメントを LE 表記に更新
    - TestPackFloat32LE を新規追加 (4ケース + roundtrip 検証)
    - CI test ターゲットを ./test/... → ./... に変更し pkg/calibration/ を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
2026-03-13 feat: LED cmd 0x05→0x30 (ch+duty形式), CI修正 (closes #25)
    - firmware/src/protocol.c: case 0x05 → 0x30, data[ch, duty]形式に変更
    LED2(PC3)が常に消灯していたバグを修正(Issue #25)
    - software/config/config.go: CMD_LED_SET = 0x30
    - software/pkg/device/controller.go: SetLED(ch, duty uint8)に変更
    - software/app.go: SetLED(ch, duty uint8)に変更
    - software/frontend/src/wails.ts: SetLED(ch, duty: number)に型定義更新
    - software/frontend/src/components/LEDControl.tsx: LED1/LED2独立スライダー
    - software/test/packet_test.go: 0x30コマンドでled1_set/led2_setを検証
    - firmware/test/test_led.py: 0x30形式に更新, LED1/LED2独立スイープ
    - firmware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
    [protocol.c, test_led.py]
2026-04-09 refactor: Makefile/build.sh 削除、ビルド設定整理
    ビルドスクリプトは冗長なので削除。wails build / wails dev を直接使用する。
    CLAUDE.md を Wails v2 の実態に合わせて更新。
2026-09-25 software: remove duplicated CRC8/packet implementation (#19)
    pkg/device/packet.go had a second copy of Packet/CRC8/Marshal/Unmarshal
    that nothing used. Keep pkg/serial as the single implementation and turn
    the device versions into thin aliases. Add a CRC-8 check-value test.
    Claude-Session: https://claude.ai/code/session_019y9pHp88tpZMZ3oUWqfwvk
2026-09-25 software: fix NTC temperature calculation; document sensor scales (#26, #41)
    The NTC sits on the low side of a 5.1k pull-up (firmware/docs/constants.txt),
    so R_ntc = R_series * raw / (4095 - raw). The old code used the 22k NTC
    nominal value as the divider resistor and inverted the ratio, which made
    room temperature read ~61°C. Add TEMP_SERIES_R and a unit test.
    Also document the derivation and units of VOLTAGE_SCALE / CURRENT_SCALE
    (10 mΩ shunt, PGA x32) and fix the remaining 20 mΩ mentions in README.md
    and docs/PINASSIGN_VERIFIED.csv.
    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
    [PINASSIGN_VERIFIED.csv]
2026-09-25 software: stop rx busy loop, add sensor timeout, enlarge rx queue (#55, #16, #22)
    - processorLoop: detect the closed rxChan with the two-value receive and
    disable that select case (nil channel) instead of spinning at 100% CPU.
    - Controller: SensorData.Valid is cleared when no sensor response arrives
    for SENSOR_TIMEOUT_MS (2 s). The Kalman filters are reset on the first
    response after a timeout so a reconnect does not blend in old values.
    The frontend hides stale values and shows "No sensor data" instead.
    - serial.Manager: rx queue 16 -> 128 packets; drops are counted and the
    running total is logged (DroppedPackets()).
    Claude-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
2026-09-25 software: send LED2 duty so MCU_LED2 can be turned on (#25)
    SetLED only sent one byte, so the firmware's `len >= 2` branch that calls
    LED2_SetDuty() was never reached. SetLED now takes (duty1, duty2) and
    always sends both bytes; the LED panel has a slider per LED.
    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
2026-09-25 software: limit servo pulse range to firmware default 500-2500 µs (#56)
    The UI offered 0-3000 µs but the firmware silently clamps to the calibrated
    range (default 500-2500 µs). Align SERVO_MIN_PULSE/SERVO_MAX_PULSE and the
    slider range with the firmware defaults, and clamp the lower bound in
    Controller.SetServo as well.
    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
2026-09-25 software: prefer the board's USB port when probing, rank Windows COM ports (#57)
    tryConnect now uses enumerator.GetDetailedPortsList() (falls back to plain
    port names on failure) and probes ports in this order:
    USB with WCH VID 0x1A86 > other USB > ttyUSB > ttyACM/COM* > others > ttyS
    Previously all Windows COM ports shared the default priority, so Bluetooth
    SPP and other devices could be probed before the board.
    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
2026-09-25 firmware/software: enforce the 128-byte maximum packet size (#15)
    - protocol.h: PKT_MAX_LEN (128) / PKT_MAX_DATA_LEN (122) replace the magic
    128 used for the parser buffer.
    - Process_Byte: a Length field > PKT_MAX_DATA_LEN is rejected right away
    and the parser resyncs on the next header (it previously kept buffering
    until the 128-byte guard reset it mid-packet).
    - Send_Packet: refuse len > PKT_MAX_DATA_LEN instead of overrunning the
    local pkt[128] buffer.
    - software: MAX_PACKET_LEN / MAX_DATA_LEN; Manager.Send returns an error
    for oversized packets instead of sending them.
    Claude-Session: https://claude.ai/code/session_019y9p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
    [protocol.c]
2026-09-25 firmware: fix config flash write, add CRC and min/max validation (#11, #43)
    Config_Save() called FLASH_ROM_WRITE() with sizeof(Config_t) (60 bytes),
    but FLASH_ROM_WRITE only accepts a 256-byte multiple and returns
    FLASH_ALIGN_ERROR otherwise. The return value was ignored, so the config
    (device_id, role, calibration) was never actually written to flash.
    - Config_Save: erase/write a full 256-byte page with FLASH_ROM_ERASE /
    FLASH_ROM_WRITE, check both return values and read back to verify.
    Returns 1 on success, 0 on failure.
    - Config_t.crc: CRC-32 over all preceding fields, set by Config_SetDefault
    and Config_Save, verified by Config_Load.
    - Config_Load: fall back to defaults when magic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
    [protocol.c]
2026-09-25 software: send calibration floats little-endian as the firmware expects (#20)
    PROTOCOL.md specifies slope/intercept of CMD 0x07 as little-endian float32
    and the firmware memcpy()s the bytes directly into float fields on the
    little-endian CH32X035, but the GUI packed them big-endian, so every saved
    slope/intercept was byte-swapped garbage. Pack them little-endian.
    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
2026-09-25 software: validate feedback samples during calibration (#24)
    sampleFB used whatever GetSensorData() returned, so it averaged stale
    values when the device stopped answering and accepted readings from an
    unconnected feedback line.
    - Each sample must come from a new, valid sensor response received after
    sampling started; give up after CAL_SAMPLE_TIMEOUT_MS without one.
    - Reject raw feedback values outside CAL_FB_RAW_MIN..CAL_FB_RAW_MAX
    (0.1-3.2 V at the ADC), which indicates an open/shorted feedback wire.
    - SensorData now carries RawFB; errors abort the calibration with a message.
    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
2026-09-25 firmware: keep servos free at power-up instead of driving 1500 µs (#27)
    Servo_Init() started every PWM channel at PWM_DEFAULT = 1500 µs, so a
    mechanism with a hard stop at that position stalled and heated up from
    power-on until the host sent a command. Start with CCR = 0 (output LOW,
    same as Servo_Free); each channel is driven once 0x01 / 0x03 arrives.
    Documented in PROTOCOL.md.
    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
    [servo.c]
